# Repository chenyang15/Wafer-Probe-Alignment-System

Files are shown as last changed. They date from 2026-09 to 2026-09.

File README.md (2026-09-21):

# Vision-Guided Automated Probe Alignment System for Wafer-Level Testing

A low-cost (~$200 USD), fully integrated system that automates micron-scale alignment between tungsten microprobes and semiconductor bond pads for wafer-level electrical testing — built as a Final Year Project in Robotics & Mechatronics Engineering at Monash University Malaysia, and awarded **Best FYP Report** by the department.

Commercial probe stations solve this alignment problem with proprietary vision systems and high-resolution servo stages costing $50,000–$500,000, putting them out of reach for teaching labs and small/medium enterprises. This project builds a functional equivalent from off-the-shelf components and 3D-printed parts, combining a custom motorised XY stage, a YOLOv11-based vision pipeline, magnetic encoder feedback, and an automated microprobe mechanism into a single reproducible, open-source workflow.

<div align="center">
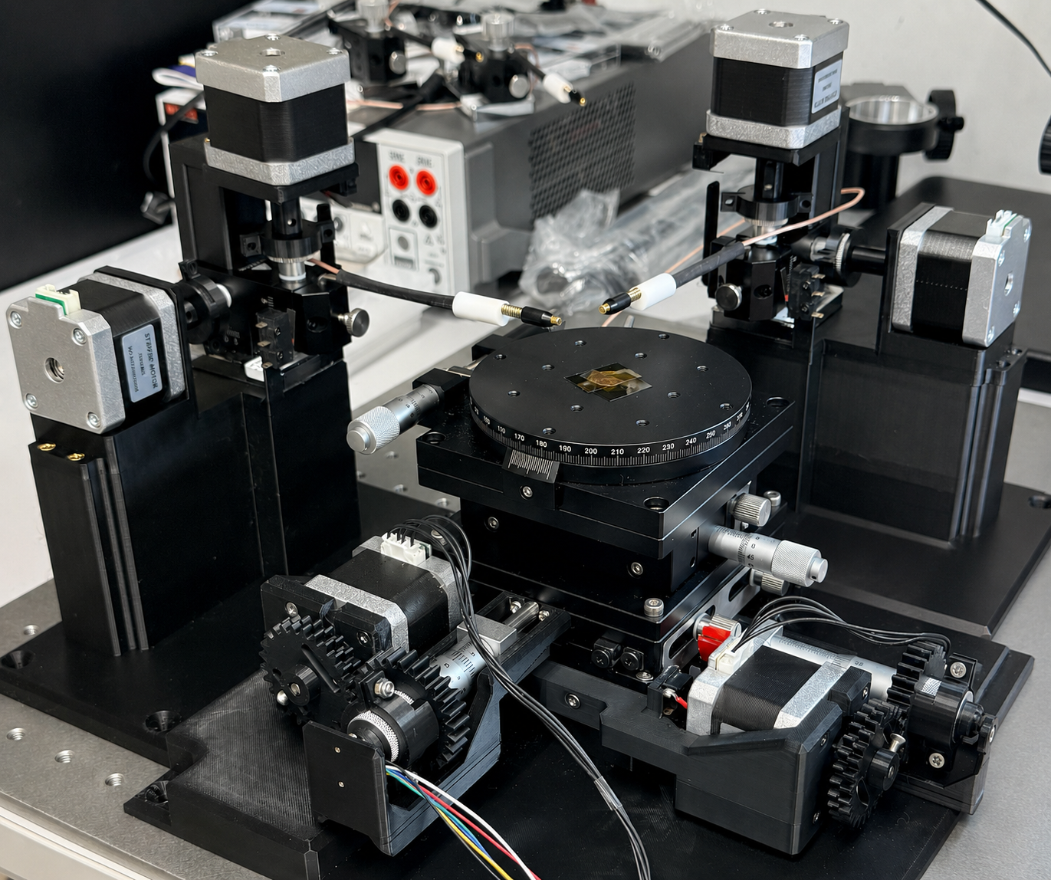
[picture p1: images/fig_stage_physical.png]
Physical build of the probe alignment system
  
</div>

## What it does

1. Drives a custom motorised XY stage using 3D-printed anti-backlash gear couplings and NEMA17 steppers
2. Automatically scans the wafer, using YOLOv11 to detect all bond pads in real time — reliably, even on damaged or oxidised pads where classical template matching fails outright
3. Computes device (crossbar) centre coordinates from detected pads and stores them in a persistent registry with a live wafer minimap
4. Recentres the stage on any selected device using a three-stage correction chain — encoder drift correction, magnetic encoder step correction, and two-pass image-guided fine centering — pushing positioning error from ~300 µm down to **below 43 µm**
5. Drives a two-axis microprobe mechanism to make electrical contact with the aligned device

The system breaks down into three major phases — live bond pad detection, device centering, and automated probing:

<div align="center">
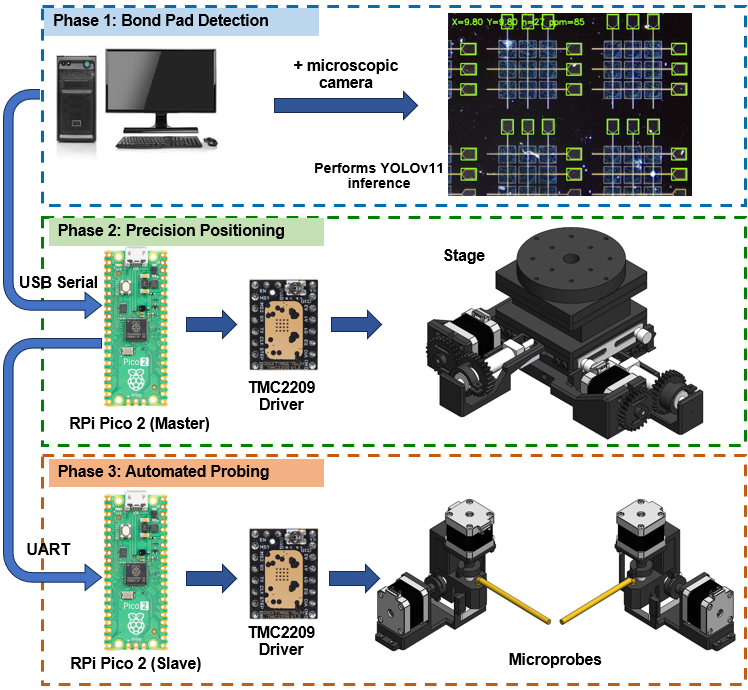
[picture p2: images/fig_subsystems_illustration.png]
Three major subsystems: detection, centering, probing
  
</div>

## System Architecture

Four subsystems, coordinated over USB serial:

- **Motorised XY wafer stage** — driven by NEMA17 steppers through custom 3D-printed spring-loaded split-gear anti-backlash couplings. 25 mm travel per axis, 0.156 µm/step theoretical resolution at 16× microstepping.
- **Firmware (Raspberry Pi Pico 2W / RP2350A)** — PIO-based, dual-core motion control (Core 0: USB serial + X-axis, Core 1: Y-axis) for jitter-free, simultaneous XY motion via TMC2209 stepper drivers. Trapezoidal S-curve motion profiles, safe homing logic, and MT6835 21-bit magnetic encoder integration for closed-loop correction.
- **Vision & scan pipeline (host, PySide6 desktop app)** — a YOLOv11 model (replacing an earlier OpenCV template-matching approach that failed on damaged/oxidised pads) detects bond pads per frame; a phase-correlation calibration procedure maps pixel space to stage space; an automated unidirectional scan builds a full device registry.
- **Microprobe mechanism** — two independently-actuated probe carriages (one per crossbar bus line), each with a lateral axis and a Z-axis for pad contact, mounted symmetrically on the stage base.

<p align="center">
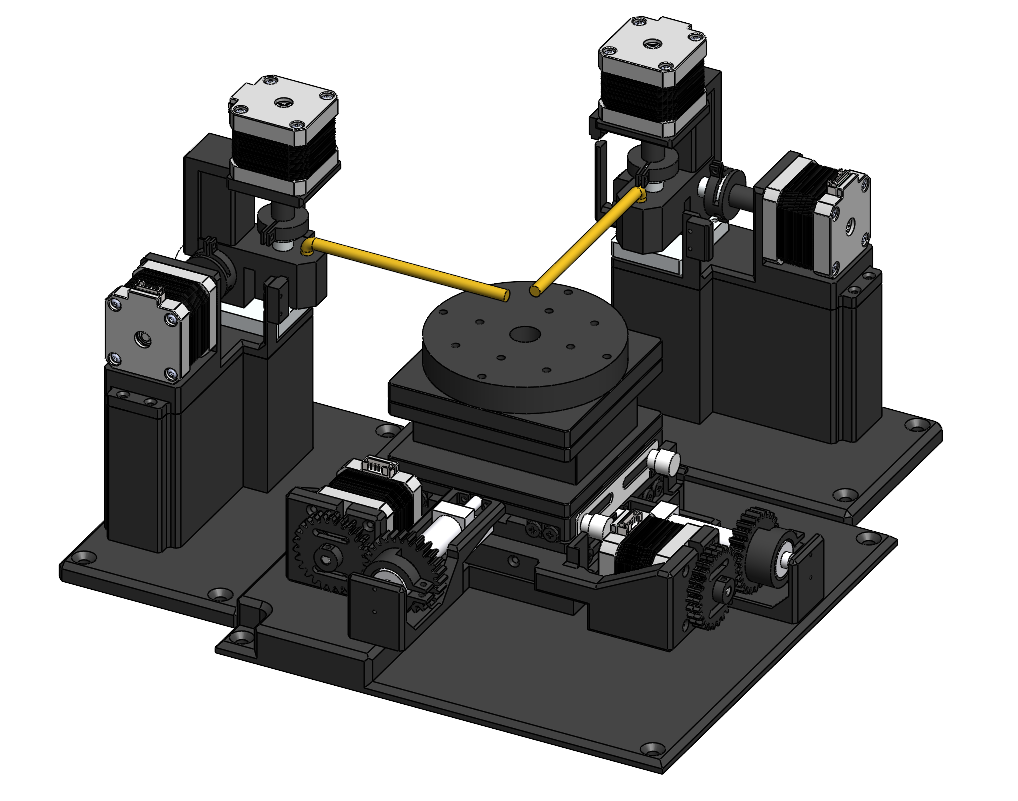
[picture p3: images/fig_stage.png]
Full CAD assembly including microprobe mechanism
  
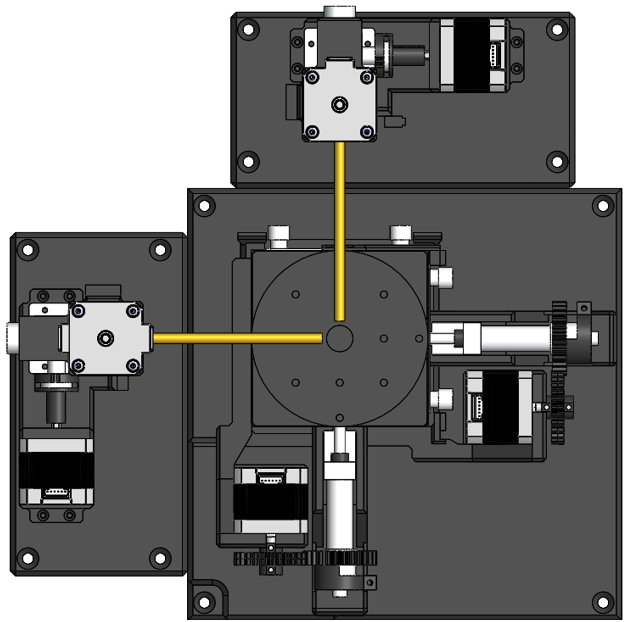
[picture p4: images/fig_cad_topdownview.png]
Top-down CAD view of the stage
  
</p>

### Desktop Application

The host runs a PySide6 desktop application that manages the live camera feed, orchestrates scans, and runs YOLO inference — the same interface used to trigger scans, review the wafer minimap, and send the stage to any detected device.

<p align="center">
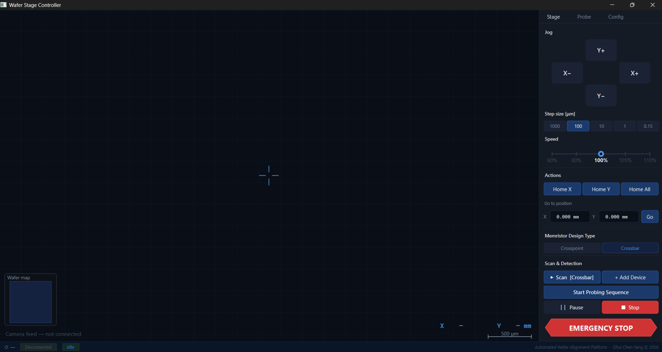
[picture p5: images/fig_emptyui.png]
Desktop UI before a scan, empty camera feed
  
</p>

## Bond Pad Detection (YOLOv11)

Bond pads on the test wafer ranged from clean to heavily damaged and oxidised. An initial OpenCV template-matching approach failed outright on damaged pads — illumination variation and physical damage from prior probe contact both broke it. A YOLOv11 model, trained across the full range of pad conditions, detects pads reliably in every case:

<p align="center">
  Bond pad condition 1: clean
  Bond pad condition 2: light oxidation
  Bond pad condition 3: moderate damage
  Bond pad condition 4: heavy damage
</p>

Live detection during a scan, with bounding boxes drawn over every detected pad:

<div align="center">
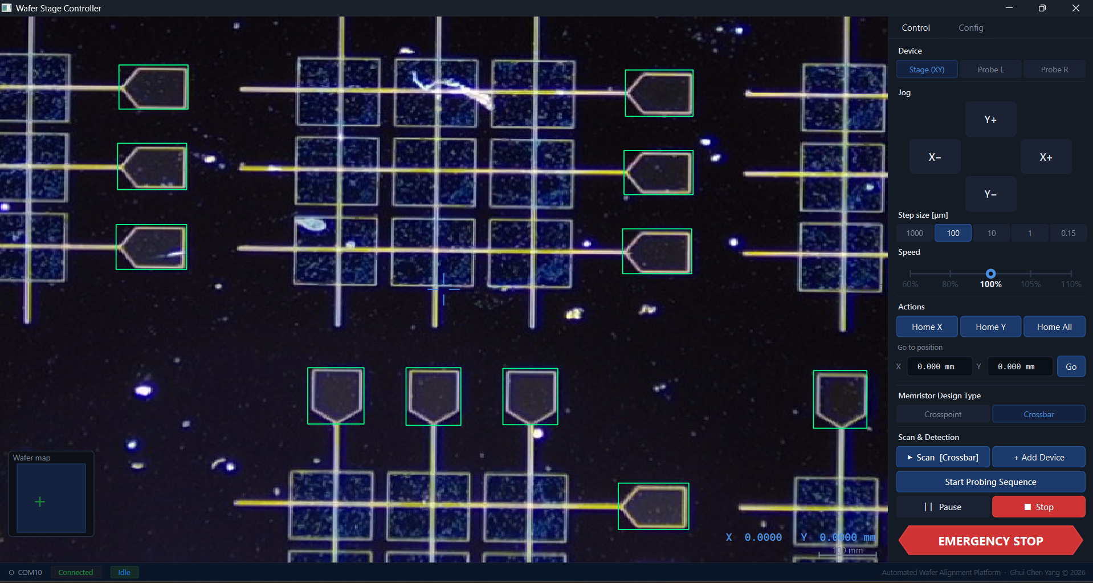
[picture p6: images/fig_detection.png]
Live YOLOv11 bounding box detection of bond pads
  
</div>

This robustness is what took full pipeline recovery to 100% across 30 repeated scans, recovering all 144 pads and all 24 device centres every time.

## Wafer Minimap

Detected devices are plotted onto a live minimap as the scan progresses, closely matching the actual layout of the physical wafer sample:

<p align="center">
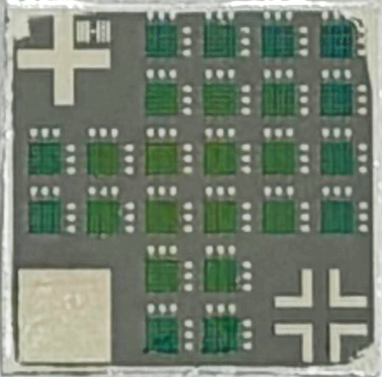
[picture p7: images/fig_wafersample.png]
Physical wafer sample
  
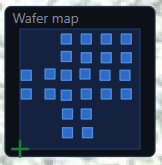
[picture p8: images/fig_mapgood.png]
Wafer minimap after scanning, showing detected device positions
  
</p>

Clicking any device on the minimap and pressing "Go To" sends the stage to recentre on that device automatically:

<div align="center">
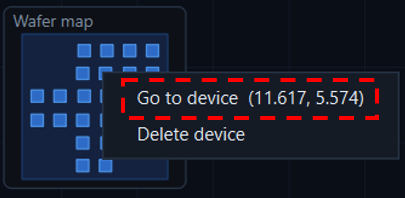
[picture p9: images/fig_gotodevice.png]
UI showing selecting a device on the minimap and pressing Go To
  
</div>

## Positioning Correction

A 15-cycle backlash test revealed a sharp asymmetry between the two stage axes: the Y axis had a small, highly repeatable systematic offset, but the X axis — which has to carry both its own stage layer and the entire Y layer above it — showed erratic scatter with individual errors up to ±150 µm. This made step-count-only positioning unusable on X.

A three-stage correction chain closes that gap, taking the stage from a rough scan-registered position down to a precisely centred device:

<div align="center">
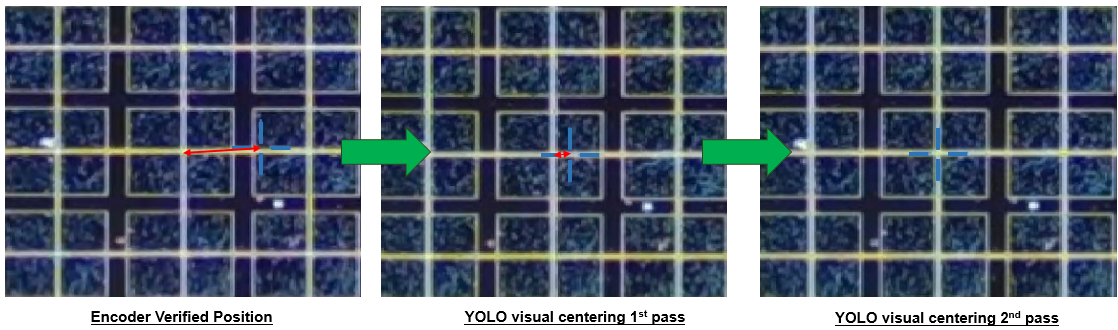
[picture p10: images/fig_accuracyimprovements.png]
Three-stage positioning accuracy improvement: encoder correction, first YOLO pass, second YOLO pass
  
</div>

1. **Encoder-verified movement** gets the stage close to the device centre
2. **First YOLO fine-centering pass** brings it substantially closer
3. **Second YOLO fine-centering pass** achieves precise centring — residual error below 43 µm

## Automated Probing

Two probe assemblies are mounted symmetrically on the stage base, one per crossbar bus line. The left probe steps along and lands on the right column of bond pads, while the right probe steps along and lands on the top row:

<p align="center">
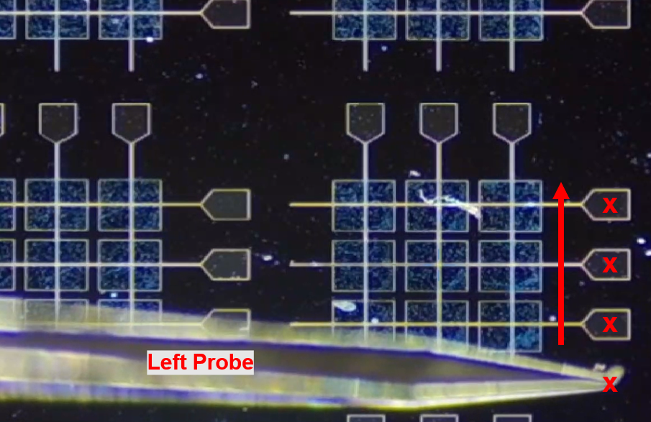
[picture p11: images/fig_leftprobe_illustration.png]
Left microprobe probing the right column of bond pads
  
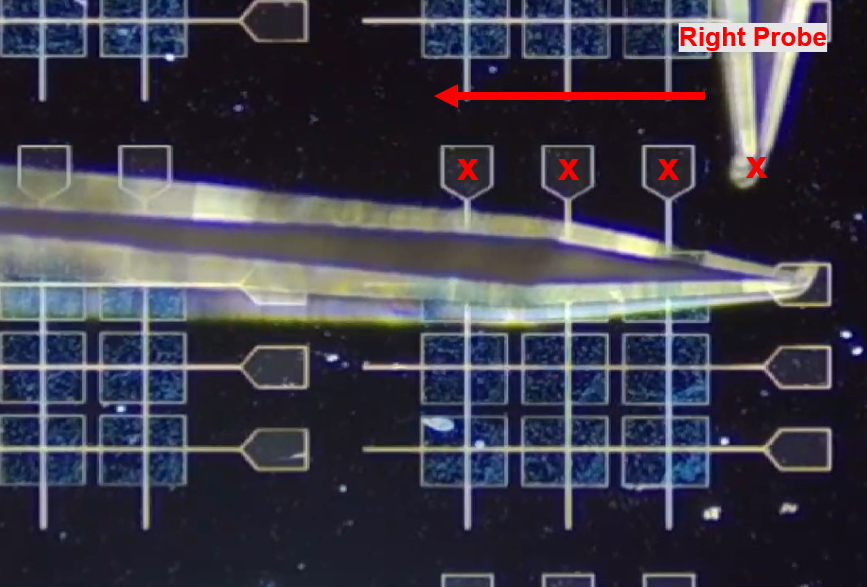
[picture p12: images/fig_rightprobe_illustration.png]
Right microprobe probing the top row of bond pads
  
</p>

Each probe assembly is a two-motorised-axis carriage — a lateral axis to step between pad positions, and a Z-axis to lower the needle onto the pad for contact. Image below shows the assembly of one side of the probe assembly.

<div align="center">
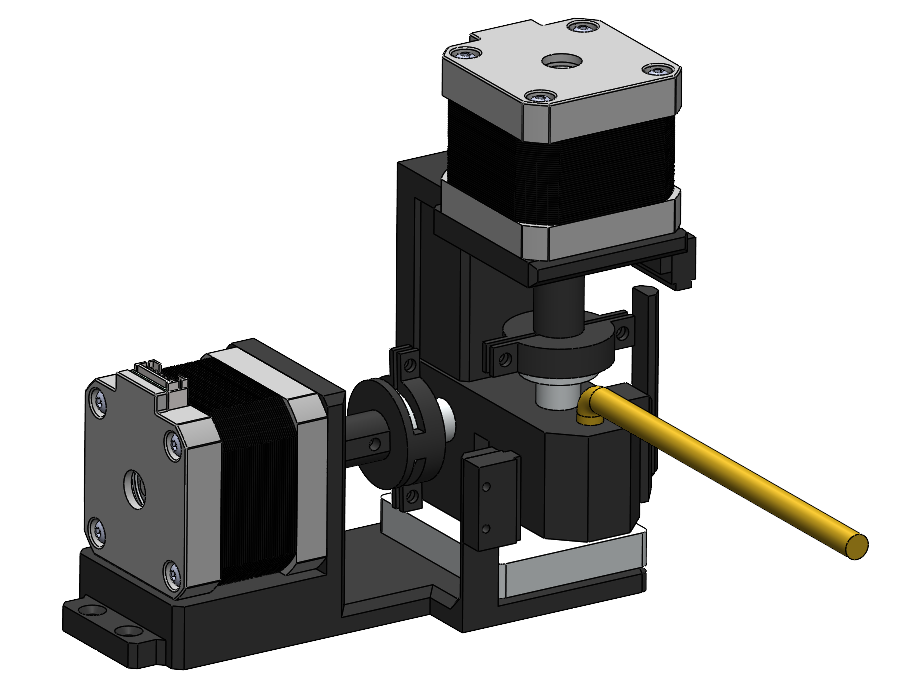
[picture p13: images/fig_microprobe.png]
CAD model of one microprobe sub-assembly
  
</div>

## See It In Action

### YOLO live detection demo
<div align="center">
  
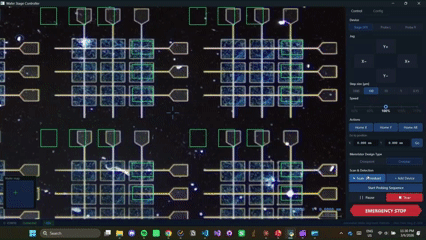
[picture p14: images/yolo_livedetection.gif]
Live YOLOv11 bond pad detection demo
  

</div>

<p align="center">
  
  https://github.com/user-attachments/assets/2e65f433-c4e1-4870-8737-4bd043e61879

</p>

### Device positioning & centering
<div align="center">
  
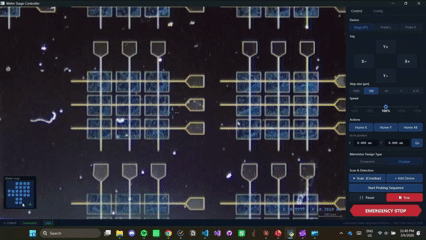
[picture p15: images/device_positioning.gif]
Device centering demo
  

</div>

<p align="center">
  
  https://github.com/user-attachments/assets/fc8239ff-43dc-4b65-8022-78ce584394f2

</p>

### Automated Probe Positioning
<div align="center">
  
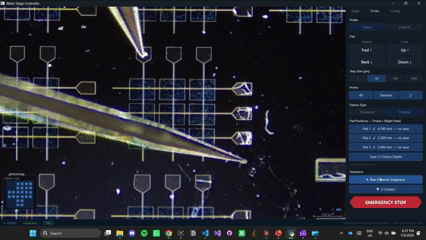
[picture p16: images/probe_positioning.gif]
Automated probe positioning demo
  

</div>

<p align="center">

  https://github.com/user-attachments/assets/283223e4-f84b-474d-8864-223d71bc67b3

</p>

## Results at a glance

| Metric | Result |
|---|---|
| Bond pad detection | All 144/144 pads and all 24/24 device centres recovered, in all 30 repeated full-wafer scans |
| YOLOv11 model | mAP@0.5 = 0.872, mAP@0.5:0.95 = 0.820, precision = 0.995, recall = 0.860 (100 epochs, 150 labelled images) |
| Final positioning accuracy | <43 µm typical residual (≤87 µm worst case) — well within the 150 µm pad half-width |
| Probe contact | 100% lateral on-pad success (150/150 pads × 2 probes) and 100% electrical contact success across 50 devices |
| Full wafer scan time | <7 minutes per full-wafer scan |
| Total hardware cost | ~$200 USD vs. $50,000–$500,000 for commercial probe stations |

## Hardware

- NEMA17 stepper motors (17HS4401) with TMC2209 drivers (StealthChop2, MicroPlyer interpolation)
- Raspberry Pi Pico 2W (RP2350A) — PIO + dual-core motion control
- MT6835 21-bit absolute magnetic rotary encoders (both axes)
- Microscopic board camera with high-magnification zoom lens
- All structural/custom parts (motor mounts, gear housings, limit switch brackets, encoder mounts, base platform) designed in CAD and 3D-printed in PLA

## Author

**Ghui Chen Yang** — Robotics & Mechatronics Engineering, Monash University Malaysia
Supervised by Dr. Patrick Ho, Department of Electrical and Computer Systems Engineering

This project was Awarded Best FYP Report for the Department of Robotics & Mechatronics Engineering.

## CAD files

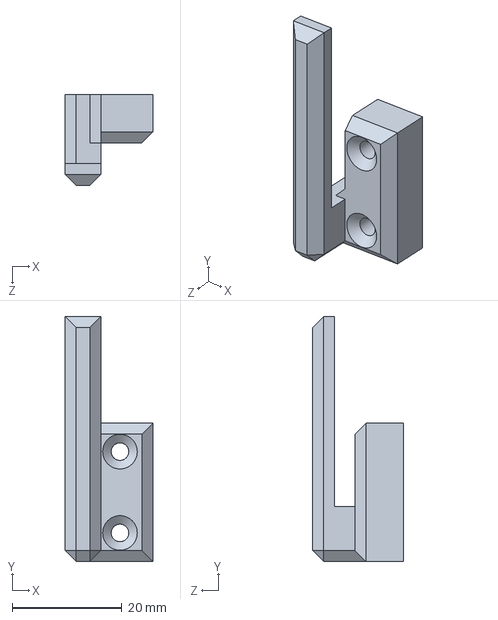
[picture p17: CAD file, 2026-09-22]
CAD-Microprobe/zclickpiece_left.SLDPRT
16.0 x 44.6 x 16.5 mm

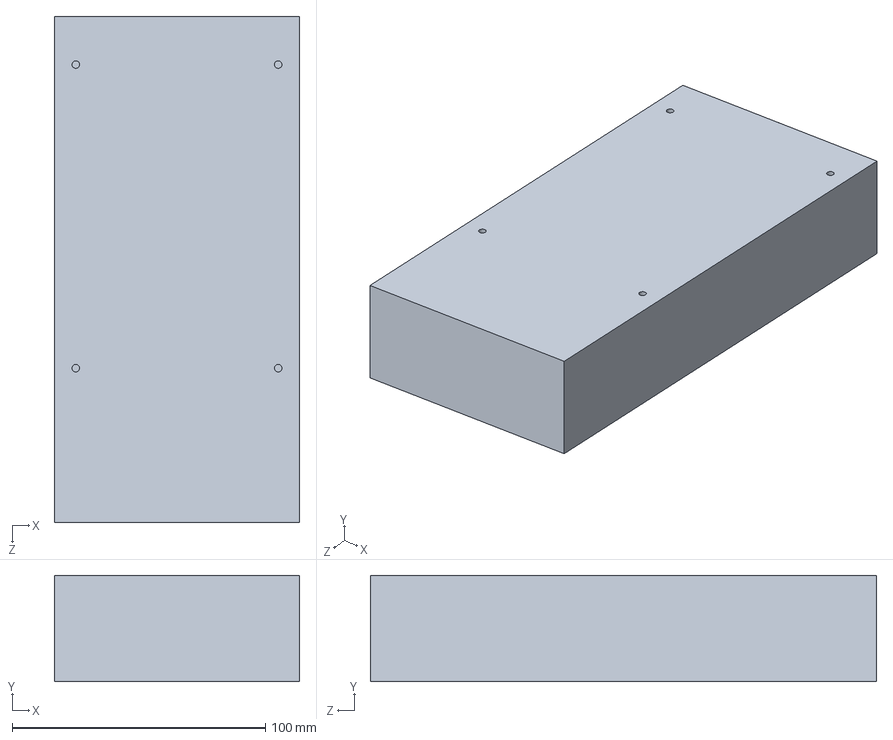
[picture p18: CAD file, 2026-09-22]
CAD-PSU/base_plate.SLDPRT
97.0 x 42.0 x 200.0 mm

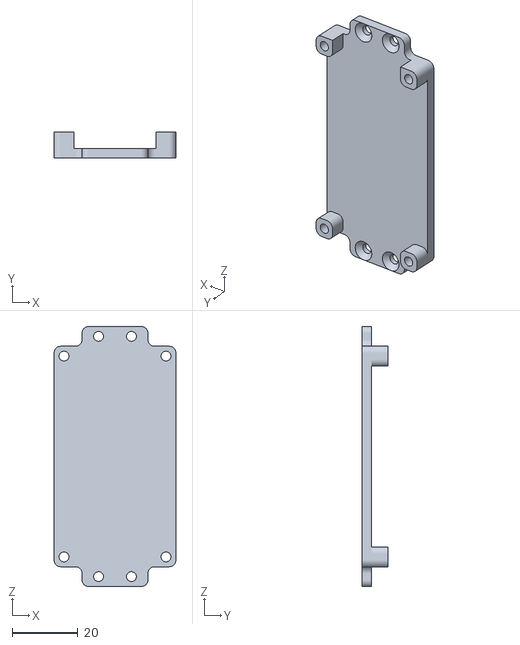
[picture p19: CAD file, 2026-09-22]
CAD-Stage/prints/buck_converter_housing_single.STL
37.0 x 8.00 x 79.0

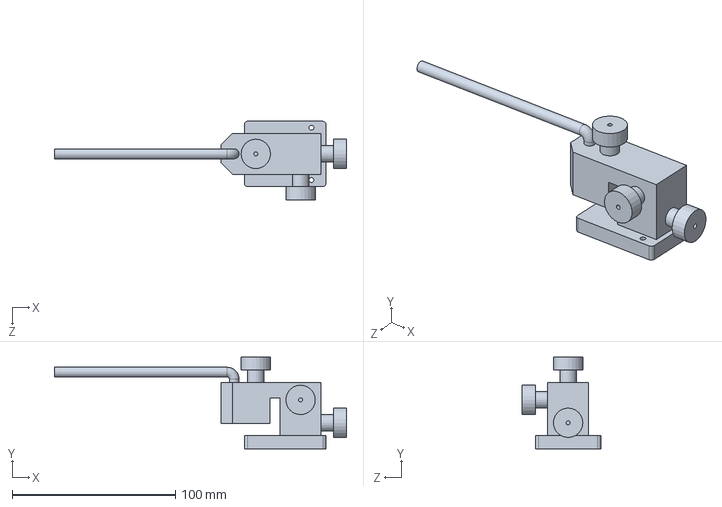
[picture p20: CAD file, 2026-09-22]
CAD-Microprobe/simple_microprobe_model_right.SLDPRT
178.7 x 56.2 x 48.1 mm

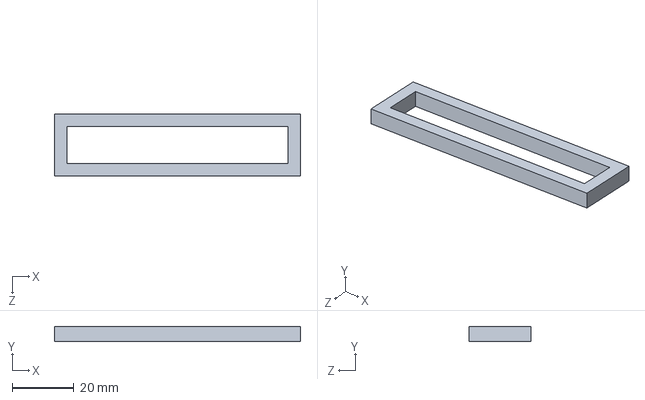
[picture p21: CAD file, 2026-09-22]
CAD-PSU/standoffs.SLDPRT
80.0 x 5.00 x 20.0 mm

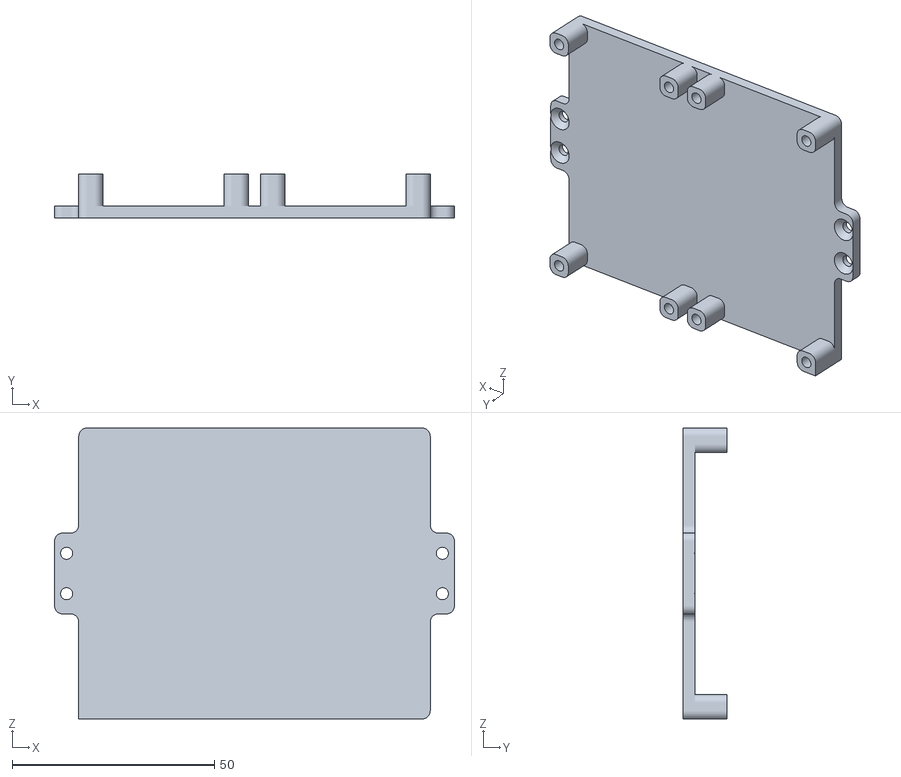
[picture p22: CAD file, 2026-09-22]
CAD-Stage/prints/buck_converter_housing.STL
99.0 x 11.0 x 72.0

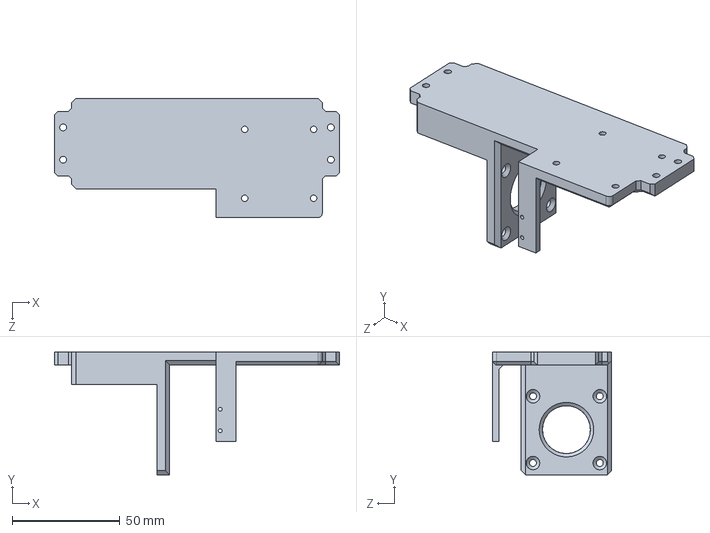
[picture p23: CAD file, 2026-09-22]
CAD-Microprobe/ystepper_mount_right_backup.SLDPRT
132.3 x 57.0 x 55.4 mm

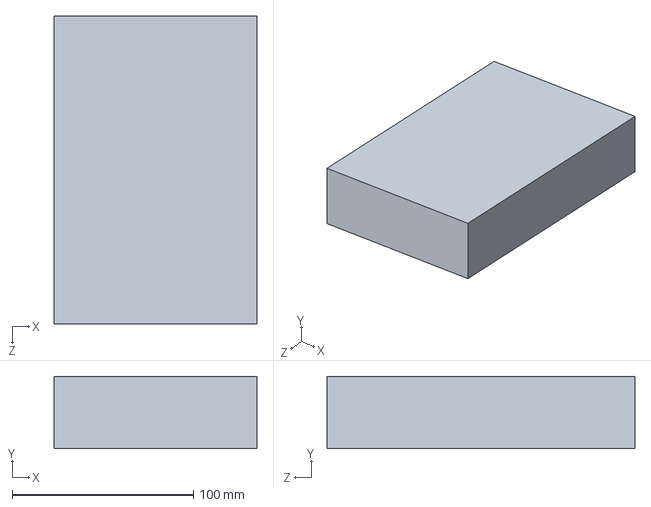
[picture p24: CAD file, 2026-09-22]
CAD-PSU/breadboardcircuit_volume.SLDPRT
112.0 x 40.0 x 170.0 mm

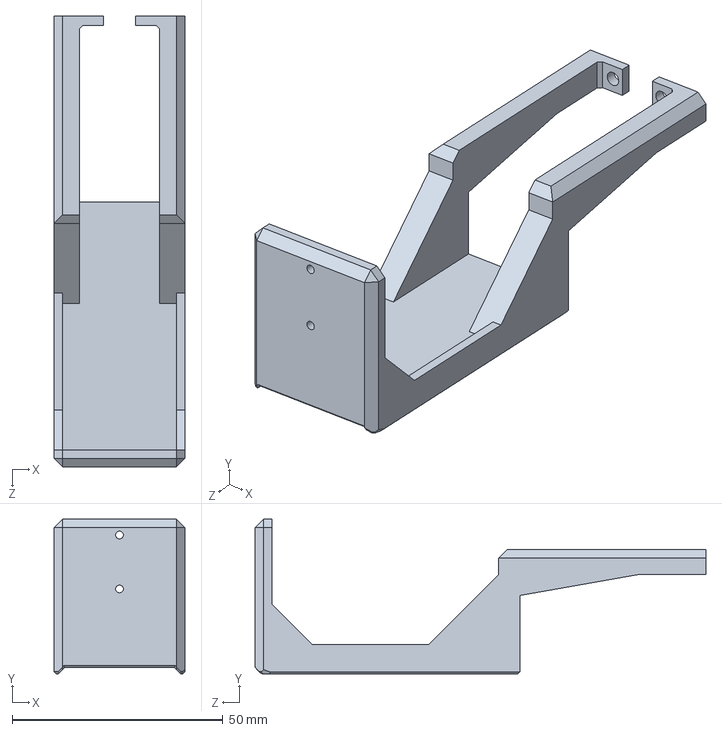
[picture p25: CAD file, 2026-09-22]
CAD-Stage/encoder_mount_xaxis.SLDPRT
31.0 x 36.7 x 107.1 mm

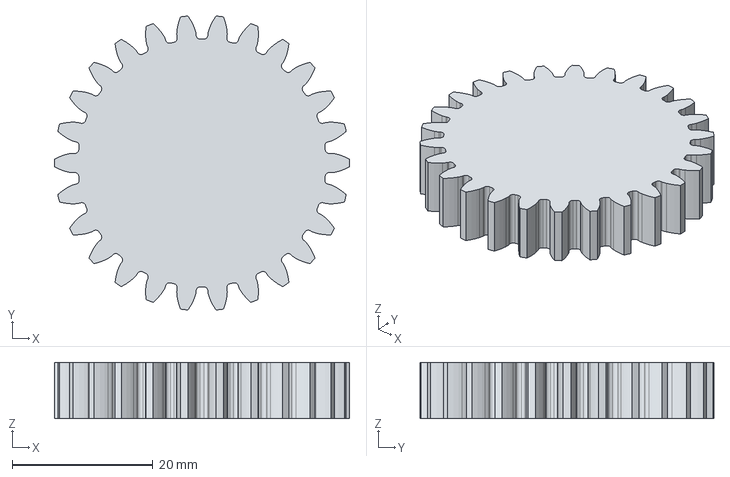
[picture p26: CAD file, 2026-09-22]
CAD-Stage/prints/gear.step
42.0 x 41.8 x 8.00 mm

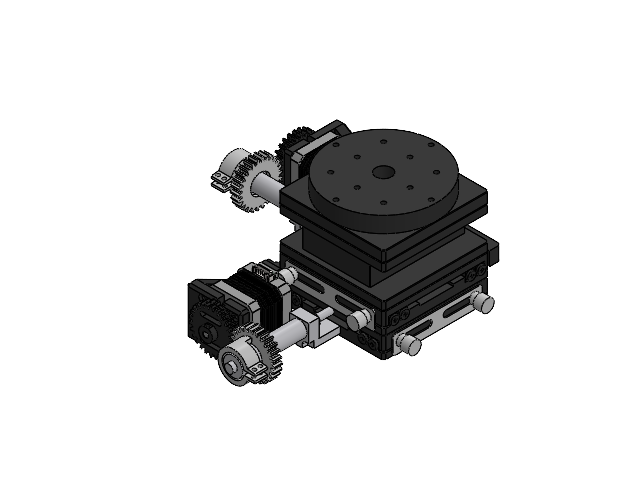
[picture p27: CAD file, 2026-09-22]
CAD-Stage/stage_assembly.SLDASM
layer1 x 2
layer2 x 2
guide rail x 8
layer3 x 2
layer4
layer5
layer6
hardstop x 2
knob x 2
Gear_Knob_Shorter x 2
rear end cap_1.step x 2
rear bearing_1.step x 2
connector_1.step x 2
shaft_1.step x 2
stator_1.step x 2
front end cap_1.step x 2
front bearing_1.step x 2
M3x10-Screw_1.step x 8
Gear_SplitAxis x 4
motormount_upperknob
motormount_lowerknob

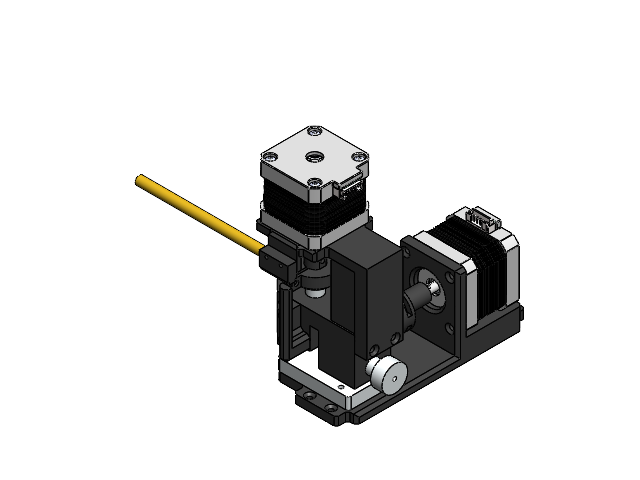
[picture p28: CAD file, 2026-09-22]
CAD-Microprobe/microprobe_assembly_left.SLDASM
simple_microprobe_model_left
couple_zstepper
zstepper_mount_left
limitswitch_dimensions x 2
zclickpiece_right
couple_ystepper
ystepper_mount_left
rear end cap_1.step x 2
rear bearing_1.step x 2
connector_1.step x 2
shaft_1.step x 2
stator_1.step x 2
front end cap_1.step x 2
front bearing_1.step x 2
M3x10-Screw_1.step x 8

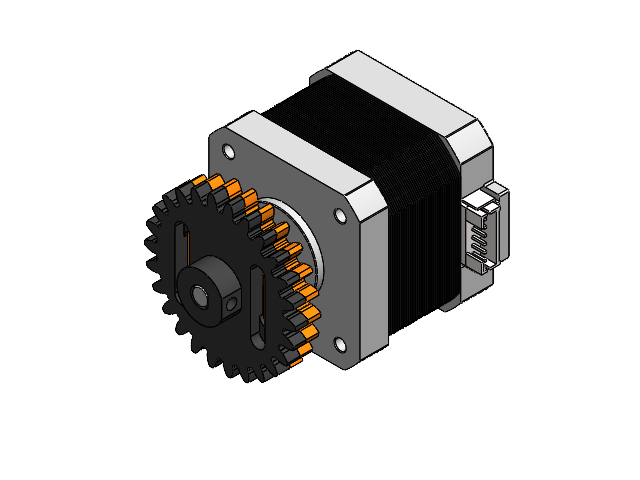
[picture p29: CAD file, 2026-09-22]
CAD-Stage/stepper_gear_assem.SLDASM
rear end cap_1.step
rear bearing_1.step
connector_1.step
shaft_1.step
stator_1.step
front end cap_1.step
front bearing_1.step
M3x10-Screw_1.step x 4
Gear_SplitAxis x 2

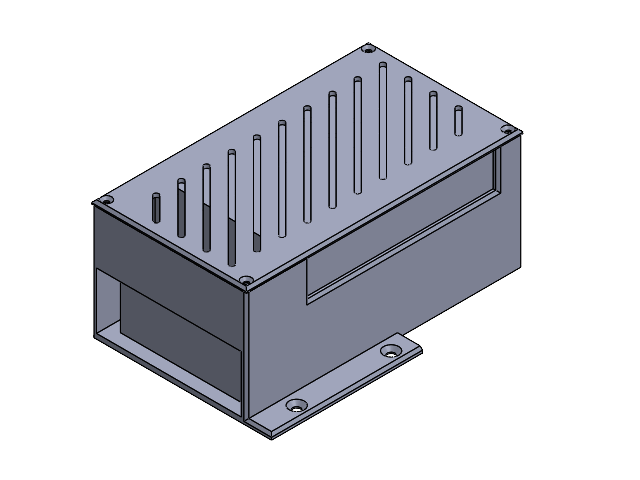
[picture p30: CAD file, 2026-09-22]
CAD-PSU/electronics_assembly.SLDASM
housing
psu
breadboardcircuit_volume
buck_converter_housing
lid

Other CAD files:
CAD-Microprobe/microprobe_assembly_right.SLDASM
CAD-Stage/axislayer.SLDASM
CAD-Stage/stage_and_baseplate.SLDASM
CAD-Stage/rear end cap_2.step.SLDPRT
CAD-Microprobe/circularpiece.SLDPRT
CAD-Microprobe/couple_ystepper.SLDPRT
CAD-Microprobe/couple_zstepper.SLDPRT
CAD-Microprobe/leftside_basemount.SLDPRT
CAD-Microprobe/limitswitch_dimensions.SLDPRT
CAD-Microprobe/microprobe_holeguide.SLDPRT
CAD-Microprobe/prints/circularpiece.STL
CAD-Microprobe/prints/couple_ystepper.STL
CAD-Microprobe/prints/couple_zstepper.STL
CAD-Microprobe/prints/leftside_basemount.STL
CAD-Microprobe/prints/microprobe_holeguide.STL
CAD-Microprobe/prints/rightside_basemount.STL
CAD-Microprobe/prints/ystepper_mount_left.STL
CAD-Microprobe/prints/ystepper_mount_right.STL
CAD-Microprobe/prints/zclickpiece_left.3mf
CAD-Microprobe/prints/zclickpiece_left.STL
CAD-Microprobe/prints/zclickpiece_right.STL
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

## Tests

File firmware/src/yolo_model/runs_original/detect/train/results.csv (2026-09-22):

epoch | time | train/box_loss | train/cls_loss | train/dfl_loss | metrics/precision(B) | metrics/recall(B) | metrics/mAP50(B) | metrics/mAP50-95(B) | val/box_loss | val/cls_loss | val/dfl_loss | lr/pg0 | lr/pg1 | lr/pg2
1 | 33.9014 | 0.95171 | 3.33822 | 0.92636 | 0.03136 | 0.53027 | 0.02447 | 0.0153 | 1.05346 | 3.33743 | 0.85553 | 0.0001 | 0.0001 | 0.0001
2 | 58.3632 | 0.75592 | 2.82719 | 0.85262 | 0.05136 | 0.86848 | 0.17237 | 0.07444 | 0.69839 | 3.37991 | 0.7964 | 0.000217822 | 0.000217822 | 0.000217822
3 | 82.7899 | 0.77192 | 2.08937 | 0.83363 | 0.05099 | 0.86221 | 0.20953 | 0.10438 | 0.73871 | 3.28067 | 0.79232 | 0.000333268 | 0.000333268 | 0.000333268
4 | 107.681 | 0.78041 | 1.58527 | 0.84507 | 0.05099 | 0.86221 | 0.20994 | 0.09497 | 0.75923 | 3.22738 | 0.80272 | 0.000446338 | 0.000446338 | 0.000446338
5 | 132.217 | 0.76414 | 1.20599 | 0.83209 | 0.05099 | 0.86221 | 0.25287 | 0.11072 | 0.7464 | 3.09934 | 0.80468 | 0.000557032 | 0.000557032 | 0.000557032
6 | 163.747 | 0.65641 | 0.92169 | 0.82571 | 0.05099 | 0.86221 | 0.57012 | 0.42693 | 0.71916 | 2.91452 | 0.81178 | 0.00066535 | 0.00066535 | 0.00066535
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

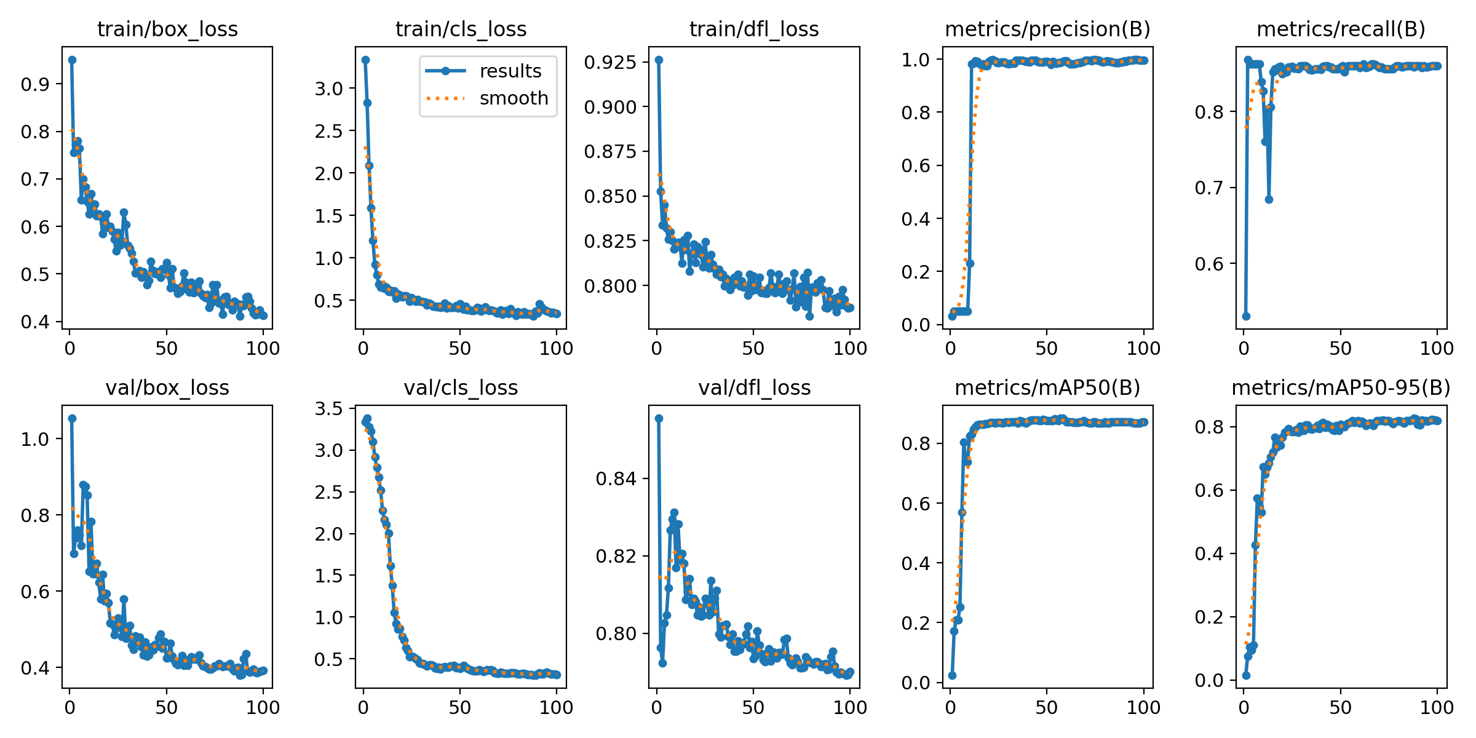
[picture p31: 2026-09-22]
firmware/src/yolo_model/runs_original/detect/train/results.png

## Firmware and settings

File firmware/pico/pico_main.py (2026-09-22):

import select
import sys
import _thread
import time
from machine import Pin, SPI, UART
import rp2

# ── Probe slave UART ───────────────────────────────────────────────────────────
# GP16 = TX (master → slave GP17 RX)
# GP17 = RX (master ← slave GP16 TX)
# timeout=5 ms — relay loop reads in small chunks; not a blocking readline.
probe_uart = UART(0, baudrate=115200, tx=Pin(16), rx=Pin(17), timeout=5)

# ── Motion constants ───────────────────────────────────
MICROSTEPS    = 16
STEPS_PER_REV = 200 * MICROSTEPS
MM_PER_REV    = 0.5
STEPS_PER_MM  = STEPS_PER_REV / MM_PER_REV   # 6400 steps/mm

MIN_SPEED  = 2000    # steps/sec — above resonance zone (~31–80 full steps/sec for NEMA17)
MAX_SPEED  = 13043   # steps/sec (100% speed)
ACCEL      = 40000   # steps/sec²  — gentle enough for both motors to track reliably
HOME_SPEED = 13043   # always home at 100% regardless of UI setting

SPEED_PRESETS = {
    0: 7826,    # 60%
    1: 9130,    # 70% — used for scanning (reduces X vibration and lead-screw resonance)
    2: 10435,   # 80%
    3: 13043,   # 100%
    4: 14348,   # 110%
}

# ── Encoder constants ──────────────────────────────────
# ENC_DIR = +1  →  raw angle INCREASES when stage moves AWAY from home (positive direction).
# ENC_DIR = -1  →  raw angle DECREASES when stage moves away from home.
# Verified by manual test: moving away from home increases raw count on both axes.
ENC_DIR_X = 1
ENC_DIR_Y = 1

ENC_COUNTS_PER_REV = 2_097_152   # 2^21  (MT6835 21-bit)
ENC_HALF           = 1_048_576   # half revolution, used for wrap-safe arithmetic

# After a commanded move, correct if encoder error exceeds this threshold.
# Set to 0 to disable correction entirely.
CORR_THRESHOLD_MM = 0.050   # 50 µm threshold — active for MOVETO (device goto only)
MAX_CORR_MM       = 0.200   # never correct more than 200 µm in one shot

# ── Motor pins ─────────────────────────────────────────
M1_DIR=2; M1_STEP=3; M1_EN=4; M1_MIN=18; M1_MAX=19
M2_DIR=5; M2_STEP=6; M2_EN=7; M2_MIN=20; M2_MAX=21

m1_dir=Pin(M1_DIR,Pin.OUT); m1_en=Pin(M1_EN,Pin.OUT)
m1_min=Pin(M1_MIN,Pin.IN,Pin.PULL_UP)
m1_max=Pin(M1_MAX,Pin.IN,Pin.PULL_UP)
m2_dir=Pin(M2_DIR,Pin.OUT); m2_en=Pin(M2_EN,Pin.OUT)
m2_min=Pin(M2_MIN,Pin.IN,Pin.PULL_UP)
m2_max=Pin(M2_MAX,Pin.IN,Pin.PULL_UP)
m1_en.low(); m2_en.low()

# ── Encoder SPI ────────────────────────────────────────
# SCK=GP14  MOSI=GP11  MISO=GP12  CS_X=GP9  CS_Y=GP13
# MT6835 needs SPI Mode 3 (CPOL=1, CPHA=1).
spi = SPI(1, baudrate=1_000_000, polarity=1, phase=1,
          sck=Pin(14), mosi=Pin(11), miso=Pin(12))
enc_cs_x = Pin(9,  Pin.OUT, value=1)
enc_cs_y = Pin(13, Pin.OUT, value=1)

# Home-position encoder angles, recorded at the end of each HOME command.
enc_home_angle = {'x': 0, 'y': 0}
enc_calibrated = {'x': False, 'y': False}

# ── PIO step pulse ─────────────────────────────────────
PIO_CYC = 23

@rp2.asm_pio(set_init=rp2.PIO.OUT_LOW)
def step_pulse():
    pull(block)
    mov(x, osr)
    label("loop")
    set(pins, 1) [10]
    set(pins, 0) [10]
    jmp(x_dec, "loop")

def pio_freq(steps_per_sec):
    return max(MIN_SPEED * PIO_CYC, min(60_000_000, int(steps_per_sec * PIO_CYC)))

# ── Shared state ───────────────────────────────────────
position = {'x': 0.0, 'y': 0.0}

y_req = {'steps': 0, 'direction': 0, 'speed': 0,
         'stop_pin': None, 'active': False, 'done': True,
         'is_corr': False}   # True = correction move; y_thread skips position update

def limit_hit(pin):
    return pin.value() == 1

# ── MT6835 encoder read ────────────────────────────────
def read_angle(cs):
    """
    Burst-read 21-bit angle.  TX: [0xA0, 0x03, 0,0,0,0]
    Returns 0–2097151, or -1 if the encoder is not responding.
    Only call from Core 0.
    """
    tx = bytearray([0xA0, 0x03, 0x00, 0x00, 0x00, 0x00])
    rx = bytearray(6)
    cs.value(0)
    time.sleep_us(2)
    spi.write_readinto(tx, rx)
    time.sleep_us(2)
    cs.value(1)
    if rx[2] == 0xFF and rx[3] == 0xFF and rx[4] == 0xFF:
        return -1
    return ((rx[2] << 13) | (rx[3] << 5) | (rx[4] >> 3)) & 0x1FFFFF

def set_encoder_home(axis):
    """Record current encoder angle as the zero reference.  Call after homing."""
    cs = enc_cs_x if axis == 'x' else enc_cs_y
    raw = read_angle(cs)
    if raw >= 0:
        enc_home_angle[axis] = raw
        enc_calibrated[axis] = True
        print(f"ENC_HOME:{axis.upper()}={raw}")
    else:
        enc_calibrated[axis] = False
        print(f"ENC_WARN:{axis.upper()}_NO_RESPONSE")

def enc_angle_from_home(axis):
    """
    Read the current encoder angle relative to the home position.
    Returns an integer in [0, ENC_COUNTS_PER_REV), or -1 if not calibrated
    or encoder not responding.  Identical to the angle_from_home computation
    inside enc_error_mm — factored out so it can be called independently.
    """
    if not enc_calibrated[axis]:
        return -1
    cs      = enc_cs_x if axis == 'x' else enc_cs_y
    enc_dir = ENC_DIR_X if axis == 'x' else ENC_DIR_Y
    raw = read_angle(cs)
    if raw < 0:
        return -1
    return ((raw - enc_home_angle[axis]) * enc_dir) % ENC_COUNTS_PER_REV

def enc_abs_mm(axis):
    """
    Return the absolute encoder-measured position in mm.

    Strategy: use the step-count position to determine the correct whole-revolution
    number, then replace the sub-revolution part with the precise encoder reading.
    This gives true physical position accurate to encoder resolution (~0.24 nm)
    as long as step-count error is less than ±0.25 mm (half a revolution) — which
    is always the case for our system (typical slip < 50 µm per move).

    Formula:
        sub_rev_mm  = afh / ENC_COUNTS_PER_REV × MM_PER_REV   (0 … 0.5 mm)
        whole_revs  = round((position - sub_rev_mm) / MM_PER_REV)
        abs_pos_mm  = whole_revs × MM_PER_REV + sub_rev_mm

    Returns None if encoder is not calibrated or not responding.
    """
    afh = enc_angle_from_home(axis)
    if afh < 0:
        return None
    sub_rev_mm  = afh / ENC_COUNTS_PER_REV * MM_PER_REV
    whole_revs  = int(round((position[axis] - sub_rev_mm) / MM_PER_REV))
    return whole_revs * MM_PER_REV + sub_rev_mm

def enc_error_mm(axis):
    """
    Return the signed error between the encoder-measured position and the
    step-count position, in mm.

      Positive  → stage is physically AHEAD of step-count position.
      Negative  → stage is physically BEHIND step-count position.

    Because the MT6835 is single-turn absolute, we compare fractional
    revolution only (good to ±0.25 mm — far larger than any realistic slip).
    Returns 0.0 when not calibrated or encoder not responding.
    """
    angle_from_home = enc_angle_from_home(axis)
    if angle_from_home < 0:
        return 0.0

    # Where within the current revolution the step count says we should be.
    frac_rev       = (position[axis] / MM_PER_REV) % 1.0
    expected_angle = int(frac_rev * ENC_COUNTS_PER_REV) % ENC_COUNTS_PER_REV

    # Signed difference, wrapped to ±half-revolution.
    err = angle_from_home - expected_angle
    if err >  ENC_HALF: err -= ENC_COUNTS_PER_REV
    if err < -ENC_HALF: err += ENC_COUNTS_PER_REV

    err_mm = err / ENC_COUNTS_PER_REV * MM_PER_REV
    return err_mm

def encoder_correction(axis):
    """
    After a commanded move, check the encoder error once.
    If it exceeds CORR_THRESHOLD_MM, issue ONE correction move (capped at MAX_CORR_MM).

    CRITICAL — do NOT call update_position here.
    A correction physically moves the stage to match the existing step-count position.
    position[] is already where we want to be; updating it would over-count by the
    correction amount and flip the error sign on every move → zig-zag oscillation.
    """
    if CORR_THRESHOLD_MM == 0:
        return
    err = enc_error_mm(axis)
    if abs(err) <= CORR_THRESHOLD_MM:
        return
    corr = max(-MAX_CORR_MM, min(MAX_CORR_MM, -err))
    steps = int(abs(corr) * STEPS_PER_MM)
    if steps == 0:
        return
    print(f"CORR:{axis.upper()}={corr:.4f}mm err={err:.4f}mm")

    if axis == 'x':
        direction = 1 if corr > 0 else 0
        move_accel(1, steps, direction)
        # No update_position — physical stage now matches step count
    else:
        direction = 0 if corr > 0 else 1
        y_req['steps']    = steps
        y_req['direction']= direction
        y_req['speed']    = 0
        y_req['stop_pin'] = None
        y_req['is_corr']  = True   # tells y_thread to skip its position update
        y_req['done']     = False
        y_req['active']   = True
        while not y_req['done']:
            time.sleep(0.001)

def encoder_correction_ref(axis, afh_ref):
    """
    Encoder correction using a stored angle-from-home reference instead of the
    step-count derived expected angle used by encoder_correction().

    Why this is better for repeated 'Go To Device':
      encoder_correction() computes expected_angle from position[], which can be
      wrong if step-count drift accumulated during the scan.  If that error exceeds
      ±ENC_HALF (±0.25 mm), the direction wraps and the correction makes things worse.

      With a stored reference (recorded after a successful previous goto), we compare
      the current angle_from_home directly against the reference angle_from_home.
      Since MOVETO always lands within ±0.25 mm of the target, the difference is always
      within the detection range — direction is always correct.

    Does NOT call update_position — same reasoning as encoder_correction().
    Only fires if CORR_THRESHOLD_MM > 0 (respects global correction enable/disable).
    """
    if CORR_THRESHOLD_MM == 0:
        return
    afh = enc_angle_from_home(axis)
    if afh < 0:
        return   # encoder not calibrated or not responding

    err = afh - afh_ref
    if err >  ENC_HALF: err -= ENC_COUNTS_PER_REV
    if err < -ENC_HALF: err += ENC_COUNTS_PER_REV
    err_mm = err / ENC_COUNTS_PER_REV * MM_PER_REV

    print(f"CORR_REF:{axis.upper()} afh={afh} ref={afh_ref} err={err_mm:.4f}mm")

    if abs(err_mm) <= CORR_THRESHOLD_MM:
        return
    corr  = max(-MAX_CORR_MM, min(MAX_CORR_MM, -err_mm))
    steps = int(abs(corr) * STEPS_PER_MM)
    if steps == 0:
        return

    if axis == 'x':
        direction = 1 if corr > 0 else 0
        move_accel(1, steps, direction)
        # No update_position — physical stage snaps to match step-count reference
    else:
        direction = 0 if corr > 0 else 1
        y_req['steps']    = steps
        y_req['direction']= direction
        y_req['speed']    = 0
        y_req['stop_pin'] = None
        y_req['is_corr']  = True   # skip position update in y_thread
        y_req['done']     = False
        y_req['active']   = True
        while not y_req['done']:
            time.sleep(0.001)

# ── Accelerated move ───────────────────────────────────
def move_accel(motor, total_steps, direction, speed=0, stop_pin=None):
    """
    Trapezoidal + S-curve move.
    Returns actual steps executed.
    """
    if total_steps <= 0:
        return 0

    if motor == 1:
        dp=m1_dir; sp=M1_STEP; sid=0
        lim_fwd=m1_min; lim_bwd=m1_max
    else:
        dp=m2_dir; sp=M2_STEP; sid=1
        lim_fwd=m2_max; lim_bwd=m2_min

    if stop_pin is None:
        if direction == 0 and limit_hit(lim_fwd):
            return 0
        if direction == 1 and limit_hit(lim_bwd):
            return 0

    dp.value(direction)
    time.sleep(0.001)

    cur_max = speed if speed > 0 else MAX_SPEED

    if stop_pin is not None:
        CHUNK = 1000
    elif total_steps <= 64:
        CHUNK = 8
    elif total_steps <= 640:
        CHUNK = 64
    else:
        CHUNK = 500   # was 200 — fewer SM reinit gaps → less Core-0 USB jitter effect

    accel_s  = int((cur_max**2 - MIN_SPEED**2) / (2 * ACCEL))
    accel_s  = max(1, min(accel_s, total_steps // 2))
    decel_s  = accel_s
    cruise_s = total_steps - accel_s - decel_s
    done     = 0

    lim_fwd_at_start = limit_hit(lim_fwd)
    lim_bwd_at_start = limit_hit(lim_bwd)

    def should_stop():
        if stop_pin is not None:
            return limit_hit(stop_pin)
        if direction == 0:
            return limit_hit(lim_fwd) and not lim_fwd_at_start
        return limit_hit(lim_bwd) and not lim_bwd_at_start

    def run_chunk(steps, spd):
        sm = rp2.StateMachine(sid, step_pulse,
                              freq=pio_freq(spd), set_base=Pin(sp))
        sm.active(1)
        sm.put(steps - 1)
        time.sleep(steps / spd + 0.0005)
        sm.active(0)

    while done < accel_s:
        if should_stop(): return done
        ch   = min(CHUNK, accel_s - done)
        prog = ((done + ch / 2) / accel_s) ** 3
        spd  = MIN_SPEED + (cur_max - MIN_SPEED) * prog
        run_chunk(ch, max(MIN_SPEED, spd))
        done += ch

    while done < accel_s + cruise_s:
        if should_stop(): return done
        ch = min(CHUNK, accel_s + cruise_s - done)
        run_chunk(ch, cur_max)
        done += ch

    while done < total_steps:
        if should_stop(): return done
        ch   = min(CHUNK, total_steps - done)
        dd   = done - accel_s - cruise_s
        prog = 1 - (1 - (dd + ch / 2) / max(1, decel_s)) ** 3
        spd  = MIN_SPEED + (cur_max - MIN_SPEED) * (1 - prog)
        run_chunk(ch, max(MIN_SPEED, spd))
        done += ch

    return done

# ── Position tracking ──────────────────────────────────
def update_position(axis, steps_taken, mm_requested):
    dist = steps_taken / STEPS_PER_MM
    if mm_requested >= 0:
        position[axis] += dist
    else:
        position[axis] -= dist

# ── Y axis thread (Core 1) ─────────────────────────────
def y_thread():
    while True:
        try:
            if y_req['active']:
                steps = move_accel(
                    2,
                    y_req['steps'],
                    y_req['direction'],
                    speed=y_req['speed'],
                    stop_pin=y_req['stop_pin'],
                )
                if y_req['stop_pin'] is None and not y_req['is_corr']:
                    mm = y_req['steps'] / STEPS_PER_MM
                    if y_req['direction'] == 1:
                        mm = -mm
                    update_position('y', steps, mm)
                y_req['is_corr'] = False
                y_req['active']  = False
                y_req['done']    = True
        except Exception as e:
            print(f"CORE1_ERR:{e}")
            y_req['active'] = False
            y_req['done']   = True
        time.sleep(0.001)

_thread.start_new_thread(y_thread, ())

# ── Move helpers ───────────────────────────────────────
def move_axis(motor, mm):
    steps = int(abs(mm) * STEPS_PER_MM)
    if steps == 0:
        return
    if motor == 1:
        direction = 1 if mm > 0 else 0
        taken = move_accel(1, steps, direction)
        update_position('x', taken, mm)
    else:
        direction = 0 if mm > 0 else 1
        y_req['steps']    = steps
        y_req['direction']= direction
        y_req['speed']    = 0
        y_req['stop_pin'] = None
        y_req['done']     = False
        y_req['active']   = True
        while not y_req['done']:
            time.sleep(0.001)

# ── Homing ─────────────────────────────────────────────
def home_x():
    print("HOMING:X")
    move_accel(1, int(200 * STEPS_PER_MM), direction=0,
               speed=HOME_SPEED, stop_pin=m1_min)
    position['x'] = 0.0
    set_encoder_home('x')
    print("HOMED:X")

def home_y_on_core1():
    """Start Y homing on Core 1 (non-blocking)."""
    y_req['steps']    = int(200 * STEPS_PER_MM)
    y_req['direction']= 1
    y_req['speed']    = HOME_SPEED
    y_req['stop_pin'] = m2_min
    y_req['done']     = False
    y_req['active']   = True

def home_y_direct():
    print("HOMING:Y")
    move_accel(2, int(200 * STEPS_PER_MM), direction=1,
               speed=HOME_SPEED, stop_pin=m2_min)
    position['y'] = 0.0
    set_encoder_home('y')
    print("HOMED:Y")
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

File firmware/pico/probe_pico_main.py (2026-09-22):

"""
probe_pico_main.py  — deploy as main.py on the probe slave Pico 2W
Microprobe motion controller: left probe (L) and right probe (R),
each with a traverse axis and a Z (vertical) axis.

Wiring
------
  UART from master Pico:  GP16 = TX, GP17 = RX  (UART0)
  Cross-connection: master GP16 → slave GP17, slave GP16 → master GP17

Axes
----
  T_L  left traverse   home = bottom of camera view   DIR GP2  STEP GP3  EN GP4   HOME GP21
  Z_L  left Z          home = top  (retracted/safe)   DIR GP5  STEP GP6  EN GP7   HOME GP20
  T_R  right traverse  home = right of camera view    DIR GP8  STEP GP9  EN GP10  HOME GP19
  Z_R  right Z         home = top  (retracted/safe)   DIR GP11 STEP GP12 EN GP13  HOME GP18

  All limit switches: NC switch to GND, PULL_UP, active HIGH (reads 1 when triggered).
  One switch per axis, at the home position only.

Direction calibration
---------------------
  DIR_TOWARD_HOME[axis] = the DIR pin value that drives the motor TOWARD its home switch.
  Default: 0 for all axes.  If a probe moves AWAY from its switch when HOME is issued,
  flip that axis from 0 → 1.

Commands (plain text, newline-terminated, received on UART)
-----------------------------------------------------------
  MOVE <axis> <mm>    relative move; returns PROBE_POS:t_l,z_l,t_r,z_r
  HOME ALL            home all four axes in sequence; returns PROBE_HOMED:* then PROBE_POS:
  HOME <axis>         home single axis; returns PROBE_HOMED:<axis> then PROBE_POS:
  POS?                returns PROBE_POS:t_l,z_l,t_r,z_r
  SPEED <idx>         accepted but ignored — fixed slow speed only
"""

from machine import Pin, UART
import time

# ── UART to master Pico ────────────────────────────────────────────────────────
uart = UART(0, baudrate=115200, tx=Pin(16), rx=Pin(17), timeout=50)

# ── Motion constants ───────────────────────────────────────────────────────────
STEPS_PER_MM  = 6400     # 16× microstepping, 0.5 mm/rev, same as master stage
MOVE_SPEED_HZ = 3000     # steps/sec — slow and safe for probe contact approach
HALF_US       = 500_000 // MOVE_SPEED_HZ   # µs per half-step period  (≈167 µs)

# ── Direction calibration ──────────────────────────────────────────────────────
# Set to the DIR pin logic level that drives the probe TOWARD its home switch.
# Flip any entry from 0→1 (or 1→0) if that axis moves the wrong way on HOME.
DIR_TOWARD_HOME = {
    'T_L': 0,   # verified: dir=1 moves toward home (bottom of camera view)
    'Z_L': 1,   # verified: dir=1 moves toward home (top / retracted)
    'T_R': 1,   # verified: dir=1 moves toward home (right of camera view)
    'Z_R': 1,   # verified: dir=1 moves toward home (top / retracted)
}

# ── Pin definitions ────────────────────────────────────────────────────────────
#                  (dir_pin,            step_pin,           en_pin,             home_pin)
try:
    _AXIS = {
        'T_L': (Pin(2,  Pin.OUT), Pin(3,  Pin.OUT), Pin(4,  Pin.OUT), Pin(21, Pin.IN, Pin.PULL_UP)),
        'Z_L': (Pin(5,  Pin.OUT), Pin(6,  Pin.OUT), Pin(7,  Pin.OUT), Pin(20, Pin.IN, Pin.PULL_UP)),
        'T_R': (Pin(8,  Pin.OUT), Pin(9,  Pin.OUT), Pin(10, Pin.OUT), Pin(19, Pin.IN, Pin.PULL_UP)),
        'Z_R': (Pin(11, Pin.OUT), Pin(12, Pin.OUT), Pin(13, Pin.OUT), Pin(18, Pin.IN, Pin.PULL_UP)),
    }
    # Enable all motors (EN active LOW on TMC2208)
    for _pins in _AXIS.values():
        _pins[2].low()
    uart.write(b"PINS_OK\n")
except Exception as e:
    uart.write(("CRASH:" + str(e) + "\n").encode())

# Tracked positions in mm (0 = at home / retracted)
_pos = {'T_L': 0.0, 'Z_L': 0.0, 'T_R': 0.0, 'Z_R': 0.0}

# ── Motion primitives ──────────────────────────────────────────────────────────

def _step(axis, steps):
    """
    Move axis by `steps` (signed: positive = away from home, negative = toward home).
    Only stops early on limit-switch trigger for toward-home moves (prevents grinding).
    Returns number of steps actually taken (always positive).
    """
    if steps == 0:
        return 0
    dir_pin, step_pin, _en, home_pin = _AXIS[axis]
    toward_home = steps < 0
    dir_val = DIR_TOWARD_HOME[axis] if toward_home else (1 - DIR_TOWARD_HOME[axis])
    dir_pin.value(dir_val)
    time.sleep_us(5)   # direction setup time

    # Block move toward home if already at the switch
    if toward_home and home_pin.value():
        return 0
    n = abs(steps)
    done = 0
    for _ in range(n):
        if toward_home and home_pin.value():
            break
        step_pin.value(1); time.sleep_us(HALF_US)
        step_pin.value(0); time.sleep_us(HALF_US)
        done += 1
    return done


def move_axis(axis, mm):
    """Relative move in mm. Positive = away from home. Updates tracked position."""
    steps = int(mm * STEPS_PER_MM)
    if steps == 0:
        return
    done  = _step(axis, steps)
    sign  = 1 if mm >= 0 else -1
    _pos[axis] = round(_pos[axis] + sign * done / STEPS_PER_MM, 6)


def home_axis(axis):
    """Drive axis toward home switch until triggered, then zero its position."""
    dir_pin, step_pin, _en, home_pin = _AXIS[axis]
    dir_pin.value(DIR_TOWARD_HOME[axis])
    time.sleep_us(5)
    while not home_pin.value():
        step_pin.value(1); time.sleep_us(HALF_US)
        step_pin.value(0); time.sleep_us(HALF_US)
    _pos[axis] = 0.0


def pos_line():
    return "PROBE_POS:{:.4f},{:.4f},{:.4f},{:.4f}".format(
        _pos['T_L'], _pos['Z_L'], _pos['T_R'], _pos['Z_R'])


def send(msg):
    uart.write((msg + "\n").encode())

# ── Command loop ───────────────────────────────────────────────────────────────
send("PROBE_READY")
_buf = b""
_beat = 0
_last_beat = time.ticks_ms()
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

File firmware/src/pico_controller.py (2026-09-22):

"""
pico_controller.py
Handles all serial communication with the Pico.
Simple rule: every public method acquires self.lock, sends a command,
reads lines until it gets the expected response or times out.
This is the same pattern that makes jog work reliably.
"""
import serial
import serial.tools.list_ports
import threading
import time


class PicoController:
    BAUD    = 115200
    TIMEOUT = 2.0   # serial readline timeout — short so we loop fast

    SPEED_PRESETS = {
        0: 7826,
        1: 9130,    # 70% — scan speed
        2: 10435,
        3: 13043,
        4: 14348,
    }

    def __init__(self):
        self.serial    = None
        self.connected = False
        self.port      = None
        self.lock      = threading.Lock()
        self.pos_x        = 0.0
        self.pos_y        = 0.0
        self.homed        = False   # True once a successful home has completed
        self.speed_idx    = 3       # default to 100% (index 3 = 13043 steps/sec)
        self.home_session = 0       # increments on every home — invalidates stored enc refs

    # ── Connection ─────────────────────────────────────

    def find_pico_port(self):
        for p in serial.tools.list_ports.comports():
            desc = (p.description or "").lower()
            mfr  = (p.manufacturer or "").lower()
            if any(k in desc or k in mfr for k in ["pico","micropython","raspberry","rp2"]):
                return p.device
            if (p.vid or 0) == 0x2E8A:
                return p.device
        for p in serial.tools.list_ports.comports():
            if "usb serial device" in (p.description or "").lower():
                return p.device
        return None

    def connect(self, port=None):
        try:
            target = port or self.find_pico_port()
            if not target:
                return False, "No Pico found"
            self.serial    = serial.Serial(target, self.BAUD, timeout=self.TIMEOUT)
            time.sleep(1.0)
            self.serial.reset_input_buffer()
            self.connected = True
            self.port      = target
            # Check if stage is already at home (both MAX switches active)
            resp = self._send("SWITCHES?", timeout=5.0)
            if resp and "M1MIN=1" in resp and "M2MIN=1" in resp:
                self.homed = True
                self.pos_x = 0.0
                self.pos_y = 0.0
            return True, target
        except Exception as e:
            self.connected = False
            return False, str(e)

    def disconnect(self):
        if self.serial and self.serial.is_open:
            self.serial.close()
        self.connected = False

    # ── Core send/receive ──────────────────────────────

    def _send(self, cmd, timeout=None):
        """Send a command, read lines until we get a recognised response.
        Returns the response line, or None on timeout/error.
        timeout defaults to self.TIMEOUT * 15 (30s) — enough for any move.
        """
        if not self.connected or not self.serial:
            return None
        if timeout is None:
            timeout = self.TIMEOUT * 15
        try:
            with self.lock:
                self.serial.reset_input_buffer()
                self.serial.write((cmd + "\n").encode())
                self.serial.flush()
                deadline = time.time() + timeout
                while time.time() < deadline:
                    line = self.serial.readline().decode(errors="ignore").strip()
                    if not line:
                        continue
                    if line.startswith(("POS:", "STATUS:", "SPEED_OK",
                                        "HOMED:", "SWITCHES:", "READY", "ERR:", "CORE1_ERR:",
                                        "ENC_AFH:", "POS_ENC:", "ENC_ABS:", "PROBE_POS:")):
                        return line
                return None
        except Exception:
            self.connected = False
            return None

    def _parse_pos(self, line):
        if line and line.startswith("POS:"):
            try:
                x, y = line[4:].split(",")
                self.pos_x = float(x)
                self.pos_y = float(y)
            except Exception:
                pass

    # ── Public API ─────────────────────────────────────

    def move(self, axis, mm):
        """Move axis by mm (relative). Blocks until done."""
        resp = self._send(f"MOVE {axis} {mm:.4f}")
        self._parse_pos(resp)
        return resp is not None

    def home(self, target="ALL"):
        """Home X, Y, or ALL. Blocks until done.
        Uses a long timeout since HOME ALL can take ~15s.
        HOME ALL sends HOMED:X, HOMED:Y, then POS:.
        HOME X / HOME Y send HOMED:X/Y then POS:.
        We wait for POS: as the single reliable terminator.
        """
        if not self.connected or not self.serial:
            return False
        try:
            with self.lock:
                self.serial.reset_input_buffer()
                self.serial.write((f"HOME {target}\n").encode())
                self.serial.flush()
                deadline = time.time() + 90.0   # 90s — plenty for simultaneous XY
                while time.time() < deadline:
                    line = self.serial.readline().decode(errors="ignore").strip()
                    if not line:
                        continue
                    if line.startswith("POS:"):
                        self._parse_pos(line)
                        self.homed        = True
                        self.home_session += 1   # all stored enc refs are now stale
                        return True
                return False
        except Exception:
            self.connected = False
            return False

    def set_speed(self, idx):
        self.speed_idx = idx
        self._send(f"SPEED {idx}", timeout=5.0)

    def goto(self, x_mm, y_mm):
        """Relative move to absolute position using step count only. Used for scanning."""
        dx = x_mm - self.pos_x
        dy = y_mm - self.pos_y
        if abs(dx) < 0.0001 and abs(dy) < 0.0001:
            return
        if abs(dx) > 0.0001 and abs(dy) > 0.0001:
            resp = self._send(f"MOVE XY {dx:.4f} {dy:.4f}")
            self._parse_pos(resp)
        elif abs(dx) > 0.0001:
            self.move("X", dx)
        else:
            self.move("Y", dy)

    def goto_verified(self, x_mm, y_mm):
        """
        Absolute move, always ensuring the final X approach is from the LEFT (rightward).
        Uses plain MOVE commands — no firmware encoder correction — so the lead-screw
        backlash state at the target matches the scan (which also always approached X
        rightward).  cx_mm values are enc_abs-corrected during the scan, so a plain MOVE
        to cx_mm delivers the correct physical position without a post-correction direction
        flip that would re-engage backlash from the wrong side.
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
